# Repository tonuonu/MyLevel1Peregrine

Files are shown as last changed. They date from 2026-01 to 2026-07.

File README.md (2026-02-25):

# Peregrine

**L2 CERTIFIED** ✓ — 22 February 2026, Enköping, Sweden

Documentation for my Tripoli Level 1 and Level 2 certification rocket build using the Apogee Peregrine dual deployment kit, named **SIPSIK** after the beloved Estonian cartoon character.

**📖 Documentation Site: [tonuonu.github.io/MyLevel1Peregrine](https://tonuonu.github.io/MyLevel1Peregrine/)**

## L2 Certification Flight

| | |
|---|---|
| **Date** | 22 February 2026 |
| **Location** | Enköping, Sweden (SMRK) |
| **Motor** | AeroTech J350 |
| **Weight** | 3100 g |
| **Expected Altitude** | 1100 m |
| **Recovery** | Dual deploy, 18" + 48" electronic (CATS Vega) |
| **Certifying Authority** | Rolf Örell (TRA# 3728) |
| **Result** | **CERTIFIED** |

## L1 Certification Flight

| | |
|---|---|
| **Date** | 24 January 2026 |
| **Location** | Enköping, Sweden (SMRK) |
| **Motor** | AeroTech H128W-14A |
| **Altitude** | 140.8 m |
| **Recovery** | Motor ejection, single chute |
| **Certifying Authority** | Rolf Örell (TRA# 3728) |
| **Result** | **CERTIFIED** |

## Repository Contents

- `docs/` — MkDocs documentation source
- `openrocket/` — OpenRocket simulation files (.ork)
- `openscad/` — 3D printable parts:
  - Nose cone with CATS Vega mount
  - Motor retainer
  - Mass dummy motors (H128W, J420R) for ground testing
- `.github/workflows/` — CI for automatic deployment

## Rocket Specs

| | |
|---|---|
| **Kit** | Apogee Peregrine |
| **Length** | 175 cm |
| **Diameter** | 100 mm |
| **Motor mount** | 38mm (29mm with adapter) |
| **Flight computer** | CATS Vega |
| **Tripoli #** | 38105 |

## Hardware

Motor casings purchased from Rolf Örell:
- **38/720** — J motors (L2 certification)
- **29/180** — H motors (L1 class)

## The Story

This blue rocket teaches my daughters Liza (5) and Elsa (2) real engineering through the Estonian cartoon character Sipsik. In the cartoon, siblings build a cardboard rocket to send their toy to the moon. Now we're doing it for real.

A small "Sipsik of Sipsik" flew on the L1 certification flight — the real doll was too valuable to risk.

## Local Development

```bash
# Install MkDocs
brew install mkdocs
pip install mkdocs-material --break-system-packages

# Serve locally
mkdocs serve

# View at http://127.0.0.1:8000/MyLevel1Peregrine/
```

## Author

[Tõnu Samuel](https://www.linkedin.com/in/tonusamuel/) — Tallinn, Estonia

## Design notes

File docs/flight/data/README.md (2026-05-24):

# Flight Data — Workflow

This directory holds raw CATS Vega flight logs and the tools to turn them into charts and analysis numbers. The workflow is designed so that **next time a flight is logged, conversion just works** — no format re-discovery needed.

## Files

| File | Purpose |
|---|---|
| `flXXX.cfl` | Raw binary flight log from CATS Vega (downloaded over USB) |
| `stXXX.txt` | CATS Configurator stats export — ground-truth max values |
| `CATS_FORMAT.md` | **Binary format specification** (read this before changing the parser) |
| `generate_charts.py` | Parser + chart generator. Strict; stops cleanly on unknown record types |
| `flXXX.summary.json` | Auto-generated per-flight summary (parser output) |
| `readme.txt` | Upstream CATS Configurator notice |

## Downloading a flight log from CATS Vega

1. Connect the CATS Vega to a computer via USB while pressing the boot button (puts it in Mass Storage Controller mode)
2. The device exposes the flash filesystem — copy `flXXX.cfl` and `stXXX.txt` for the flight(s) of interest
3. Drop both files into this directory

Up to 50 flight logs and 50 stats files are exposed per the firmware limit.

## Generating charts and analysis

```bash
cd docs/flight/data/
python generate_charts.py flXXX.cfl ../flightN_charts.png \
    --motor "AeroTech XYZ" \
    --title "Flight #N — L? Certification" \
    --json flXXX.summary.json
```

The script prints flight summary numbers (apogee, max velocity, max accel, FSM transitions) to stdout and writes the chart PNG and a JSON summary. Cross-check the JSON against `stXXX.txt` — they should agree to within rounding.

## Reproducing past flights

```bash
# L1 (Flight #1, 24 January 2026, AeroTech H128W-14A)
python generate_charts.py fl001.cfl ../flight1_charts.png \
    --motor "AeroTech H128W-14A" --title "Flight #1 — L1 Certification" \
    --json fl001.summary.json

# L2 (Flight #2, 22 February 2026, AeroTech J350)
python generate_charts.py fl002.cfl ../flight2_charts.png \
    --motor "AeroTech J350" --title "Flight #2 — L2 Certification" \
    --json fl002.summary.json
```

Expected output (verified against `stXXX.txt`):

| Flight | Apogee | Max velocity | Max accel |
|---|---|---|---|
| #1 (L1) | 141.58 m | 46.24 m/s | 4.5 g |
| #2 (L2) | 986.43 m | 172.56 m/s | 17.5 g |

## When the parser breaks

If `generate_charts.py` reports `Unknown rec_type_raw=0x…` and stops before the end of the file:

1. The CATS firmware has added or changed a record type
2. Read `CATS_FORMAT.md` for the format model
3. Find the new type definition in [catsystems/cats-embedded `recorder.hpp`](https://github.com/catsystems/cats-embedded/blob/main/flight_computer/src/flash/recorder.hpp)
4. Add an entry to the `RECORDS` dict in `generate_charts.py` (name, payload size, struct format string)
5. **Also update `CATS_FORMAT.md`** — that file is the spec, not a docstring

**Do NOT** make the parser slide bytes on unknown types. That hides the problem and produces silent garbage downstream — see `tasks/lessons.md` for the history.

## Format reference

See [`CATS_FORMAT.md`](CATS_FORMAT.md) for the complete binary format spec, FSM state enum, and hardware notes. That file is the authoritative reference — kept separate from any script so it cannot be erased by an accidental docstring edit.

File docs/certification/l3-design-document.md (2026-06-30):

# L3 Certification Design Document

**Candidate**: Tõnu Samuel (TRA# 38105)
**TAP Member #1**: Rolf Örell (TRA# 3728)
**TAP Member #2**: TBD
**Date**: February 2026 (Draft)
**Status**: DRAFT — Not yet submitted for TAP review

---

## Table of Contents

1. [Project Overview](#1-project-overview)
2. [Airframe Construction Details](#2-airframe-construction-details)
3. [Bill of Materials](#3-bill-of-materials)
4. [Recovery System](#4-recovery-system)
5. [Recovery Electronics Schematic](#5-recovery-electronics-schematic)
6. [Motor](#6-motor)
7. [Stability Analysis](#7-stability-analysis)
8. [Flight Simulations](#8-flight-simulations)
9. [Fin Flutter Analysis](#9-fin-flutter-analysis)
10. [Construction Documentation](#10-construction-documentation)
11. [L2 Flight Log](#11-l2-flight-log)
12. [Pre-Flight Checklist](#12-pre-flight-checklist)
13. [Safety Analysis](#13-safety-analysis)

---

## 1. Project Overview

### 1.1 Objective

Tripoli Level 3 high-power certification using a scratch-built rocket with a single AeroTech M1350W-PS motor, dual-deployment recovery controlled by dual redundant electronics.

### 1.2 Rocket Summary

| Parameter | Value |
|---|---|
| Name | TBD |
| Designer/Builder | Tõnu Samuel |
| Construction | Scratch-built |
| Length | TBD |
| Diameter | TBD |
| Dry weight (no motor) | TBD |
| Liftoff weight (with motor) | TBD |
| Motor | AeroTech M1350W-PS (75mm, 5178 N-s) |
| Recovery | Dual deploy, dual redundant electronics, servo-actuated spring release (mechanism TBD) |
| Expected altitude | TBD |
| Number of fins | TBD |
| Fin material | Spectrum PC CF (3D printed polycarbonate + carbon fiber) |

### 1.3 Design Philosophy

- Minimum motor class (barely M at 5178 N-s) to keep velocities and forces manageable
- Progressive flight testing on J and L motors before cert flight
- 3D printed fin can in PC CF with carbon rod reinforcement for flutter resistance
- Dual redundant electronics as required by Tripoli L3 rules
- Servo-actuated spring release instead of black powder ejection charges — mechanism under evaluation (C-latch with tongue or dual-half bayonet)
- Symmetric design: identical parts for both redundancy halves to simplify manufacturing and spares
- Single-use motor to avoid reloadable hardware risk

---

## 2. Airframe Construction Details

*Per Tripoli L3 requirement 1.a.i: Dimensioned drawings*

### 2.1 General Arrangement Drawing

*TODO: Dimensioned side-view drawing showing all major sections and dimensions*

- Overall length
- Body tube OD/ID
- Nose cone length and shape
- Fin dimensions and positions
- CP and CG locations marked
- Electronics bay location
- Recovery section layout
- Motor mount position and length
- Separation mechanism locations

### 2.2 Body Tube

| Parameter | Value |
|---|---|
| Material | TBD (commercial prebuilt tube) |
| Outer diameter | TBD |
| Inner diameter | TBD |
| Wall thickness | TBD |
| Total length | TBD |

### 2.3 Nose Cone

| Parameter | Value |
|---|---|
| Type | TBD (ogive/Von Kármán/conical) |
| Material | TBD (3D printed or commercial) |
| Length | TBD |
| Shoulder length | TBD |

Electronics may be housed in the nose cone — see section 2.8.

### 2.4 Fin Can Assembly

The fin can is 3D printed by the candidate using OpenSCAD for parametric design and Bambu P1S for printing.

| Parameter | Value |
|---|---|
| Material | Spectrum PC CF (polycarbonate + carbon fiber) |
| Number of fins | TBD |
| Fin shape | TBD |
| Root chord | TBD |
| Tip chord | TBD |
| Span | TBD |
| Thickness | TBD |
| Sweep angle | TBD |
| Reinforcement | Carbon rod channels (2× per fin, at 25% and 60% chord) |
| Infill | 70% |
| Print orientation | TBD |

**Multi-part assembly**: The fin can body is printed in multiple sections (each ≤250mm tall, Bambu P1S limit with AMS) and bonded together. Fins are printed individually and bonded to the assembled can.

### 2.5 Centering Rings and Bulkheads

| Component | Material | Dimensions | Notes |
|---|---|---|---|
| Forward centering ring | TBD | TBD | |
| Aft centering ring | TBD | TBD | |
| E-bay forward bulkhead | TBD | TBD | |
| E-bay aft bulkhead | TBD | TBD | |

### 2.6 Motor Mount

| Parameter | Value |
|---|---|
| Motor tube ID | 75mm |
| Motor tube material | TBD |
| Length | TBD (≥622mm for M1350W-PS) |
| Motor retention | TBD |

### 2.7 Motor Adapters

For pre-certification test flights:

| Adapter | For Motor | Inner Diameter |
|---|---|---|
| 75→54mm | AeroTech L1000W-18A | 54mm |
| 75→38mm | AeroTech J420R | 38mm |

### 2.8 Electronics Bay

| Parameter | Value |
|---|---|
| Location | TBD — either mid-body or nose cone |
| Length | TBD |
| Sled material | TBD |
| Switch access | External key switches (2×, one per system) |

**Nose cone option**: Placing electronics in the nose cone simplifies wiring (all forward), and the electronics mass helps CG stay forward for stability. Trade-off is accessibility and nose cone structural requirements.

**Mid-body option**: Traditional e-bay between recovery sections. Easier access, standard approach.

*TODO: Decide based on airframe layout and CG analysis.*

### 2.9 Servo and Battery Enclosures in Parachute Bay

The separation servos and their batteries must be located near the separation joints, which are inside the parachute storage bays. To prevent parachutes and shock cords from snagging on electronics hardware:

**Wall-hugging enclosure concept**: A 3D printed fairing mounts the servo and battery flush against the inner tube wall. The enclosure has a smooth, snag-free outer surface facing inward, so the parachute slides past without catching. Essentially a streamlined bump on the inside of the body tube.

| Parameter | Value |
|---|---|
| Material | Spectrum PC CF (same as other printed parts) |
| Contents per enclosure | 1 servo + 1 battery (or battery located elsewhere with wiring routed through) |
| Enclosures per joint | 2 (one per FC system, 180° apart) |
| Total enclosures | 4 (2 joints × 2 per joint) |
| Design | Parametric OpenSCAD, matched to tube ID curvature |
| Mounting | Bonded or mechanically fastened to tube wall |
| Outer surface | Smooth, radiused edges, no exposed screws or wires |

*TODO: Determine whether battery is co-located with servo in the enclosure or kept in the main e-bay with wiring routed to the servo. Co-location is simpler (shorter wires, fewer failure points) but adds mass in the parachute bay.*

### 2.10 Rail Guides

| Parameter | Value |
|---|---|
| Type | TBD |
| Quantity | TBD |
| Positions | TBD |

---

## 3. Bill of Materials

*Per Tripoli L3 requirement 1.a.ii*

### 3.1 Airframe Components

| Item | Specification | Quantity | Source |
|---|---|---|---|
| Body tube | TBD (commercial prebuilt) | TBD | TBD |
| Nose cone | TBD | 1 | TBD |
| Fin can body (printed) | Spectrum PC CF | 1 set | Printed by candidate |
| Fins (printed) | Spectrum PC CF | TBD | Printed by candidate |
| Carbon reinforcement rods | 2.0mm carbon rod | TBD | TBD |
| Centering rings | TBD | TBD | TBD |
| Motor mount tube | 75mm ID | 1 | TBD |
| Motor retainer | TBD | 1 | TBD |
| E-bay structure | TBD | 1 | TBD |
| Bulkheads | TBD | 2 | TBD |
| Rail guides | TBD | TBD | TBD |
| Shock cord | TBD | TBD | TBD |
| Quick links / hardware | TBD | TBD | TBD |

### 3.2 Recovery Components

| Item | Specification | Quantity | Source |
|---|---|---|---|
| Drogue parachute | TBD size | 1 | TBD |
| Main parachute | TBD size | 1 | TBD |
| Separation springs | TBD | TBD per joint | TBD |
| C-hooks (printed) | Spectrum PC CF, identical parts | 2 per joint (4 total) | Printed by candidate |
| Tongues (printed) | Spectrum PC CF, servo-actuated | 2 per joint (4 total) | Printed by candidate |
| Servo wall-hugging enclosures (printed) | Spectrum PC CF, matched to tube ID | 4 total (2 per joint) | Printed by candidate |
| Servos (separation) | TBD | 4 total (1 per tongue) | TBD |
| Tether cord (mechanism retention) | TBD | As needed | TBD |

### 3.3 Electronics

| Item | Specification | Quantity | Source |
|---|---|---|---|
| Primary flight computer | Custom (CATS Vega clone, improved) | 1 | Built by candidate |
| Backup flight computer | CATS Vega (original) or second custom clone | 1 | TBD |
| Battery (primary) | TBD | 1 | TBD |
| Battery (backup) | TBD | 1 | TBD |
| Key switch (primary) | TBD | 1 | TBD |
| Key switch (backup) | TBD | 1 | TBD |

### 3.4 Motor

| Item | Specification | Quantity | Source |
|---|---|---|---|
| AeroTech M1350W-PS | 75mm single-use DMS | 1 | TBD (requires L3 to purchase — sourced via TAP) |

---

## 4. Recovery System

*Per Tripoli L3 recovery requirements: parachute recovery required, dual deployment allowed with apogee destabilization event*

### 4.1 Recovery Architecture

Dual deployment using servo-actuated spring release mechanisms, controlled by dual redundant electronics:

| Event | Altitude | Device | Action |
|---|---|---|---|
| Apogee | Apogee detection | Primary FC + Backup FC | Either servo retracts its tongue → C-hook opens → springs push sections apart → drogue deploys |
| Main | TBD (e.g., 300m AGL) | Primary FC + Backup FC | Either servo retracts its tongue → C-hook opens → springs push sections apart → main deploys |

### 4.2 Separation Mechanism Concept

Instead of black powder ejection charges, separation is achieved mechanically:

1. **Springs** are preloaded between body sections during assembly, providing separation force
2. **Retention mechanism** (two identical C-latches at 180° apart) holds the sections together against the spring preload during flight
3. **Servos** retract tongues on command from the flight computer
4. Once either tongue is retracted, the C-hook at that position is an open hook holding nothing — one remaining C-latch cannot hold against the spring force alone → sections separate axially

**Why not black powder ejection charges?**

The conventional approach for HPR recovery separation uses black powder (BP) ejection charges. This design uses mechanical separation instead, for two reasons:

1. **Legal constraint (Estonia)**: Black powder is classified as an explosive under Estonian law. The candidate has no legal basis to possess even small quantities. Rocket motors are classified separately as pyrotechnics and are legally permissible. This is a hard constraint — BP-based separation is not an option for a builder based in Estonia
2. **Electronics protection**: BP charges deposit soot and combustion residue throughout the recovery bay. This rocket carries custom-built flight computers that are expensive and difficult to replace. Mechanical separation keeps the interior clean

**Additional advantages of mechanical separation**:

- Repeatable and testable — same force every time, no charge sizing uncertainty
- No hot gas near parachutes — no Nomex protectors needed
- No e-matches — simpler wiring, no igniter reliability concerns
- No pressure spike — gentler on airframe and recovery harness

### 4.3 Separation Mechanism Candidates

Two leading candidates are under evaluation. Both share the same core principle: two identical halves per joint, each controlled by one FC system, either half's release alone causes separation. The selection will be made after prototyping and discussion with Rolf.

#### Option A: C-Latch with Tongue (Preferred)

A tongue-and-groove style latch. At the separation joint, C-shaped hooks are fixed to the body sections, opening toward each other. A servo-actuated tongue fills the gap in each C-hook, locking it closed. The servo retracts the tongue to release. The analogy is a door with two locks on opposite sides and no hinges — open either lock and the whole thing falls apart.

**Operating principle:**

```
    SIDE VIEW — CROSS-SECTION AT ONE C-LATCH
    (looking at the tube wall from inside)

    LOCKED (tongue inserted)          RELEASED (tongue retracted)

    Body A       Body B               Body A       Body B
    ┌────┐       ┌────┐              ┌────┐       ┌────┐
    │    └─┐ ┌─┘    │              │    └─┐ ┌─┘    │
    │      │T│      │              │      │ │      │  ← C-hooks are open,
    │    ┌─┘ └─┐    │              │    ┌─┘ └─┐    │    nothing bridges them
    └────┘       └────┘              └────┘       └────┘

    C-hooks: passive, fixed to body sections, opening toward each other
    T = tongue: servo-actuated, fills the C-gap to lock
    Servo retracts tongue sideways → C-hooks have open mouths → sections separate

    TOP VIEW — FULL JOINT (looking down into tube)

                 C-latch #1 (FC #1)
                    ┌─┐
              ╭─────┤T├─────╮
             │     └─┘     │
         Body A             Body B
             │     ┌─┐     │
              ╰─────┤T├─────╯
                    └─┘
                 C-latch #2 (FC #2)

    Two C-latches at 180° apart
    Each has its own servo-actuated tongue
    Either tongue retracted → that C-hook is open → other latch can't hold → separation
```

**Terminology:**

| Term | Description |
|---|---|
| **C-hook** | Passive C-shaped bracket fixed to a body section. The open mouth faces the mating body section. Carries axial load only when the tongue is present to close the gap |
| **Tongue** | Servo-actuated piece that fills the C-hook gap, closing it into a closed loop. Connected to the servo arm. When retracted, the C-hook is an open hook holding nothing |
| **C-latch** | One complete latch assembly: two opposing C-hooks (one per body section) + one tongue + one servo. Two C-latches per joint, at 180° apart |

**How it works:**

- **Locked**: Tongue fills the C-hook gap on both sides. The C-hooks on Body A and Body B face each other with the tongue bridging both, creating a closed structural loop. Axial loads (thrust, drag) are transferred through the C-hook walls and tongue in compression/shear
- **Released**: Servo retracts the tongue sideways. Both C-hooks at that position now have open mouths — there is nothing connecting Body A to Body B at that point. Like removing a lock from a door with no hinges: one remaining lock on the opposite side cannot hold the door against the spring preload → sections push apart axially
- **Binary release guarantee**: Tongue in = closed loop carrying load. Tongue out = open hooks holding nothing. No force-balancing needed. The geometry guarantees separation when the tongue is retracted

**Key design properties:**

| Property | Value |
|---|---|
| C-latches per joint | 2 (at 180° apart) |
| Tongues per joint | 2 (one per C-latch, servo-actuated) |
| Total C-latches | 4 (2 joints × 2 latches) |
| Total tongues | 4 |
| Servos total | 4 (one per tongue) |
| Unique parts to design | **1 C-hook** (same part on both body sections) + **1 tongue** (connected to servo arm) |
| FC #1 controls | Tongue at C-latch #1 (drogue joint) + Tongue at C-latch #1 (main joint) |
| FC #2 controls | Tongue at C-latch #2 (drogue joint) + Tongue at C-latch #2 (main joint) |

**Advantages:**

- **Binary release**: Tongue in = locked, tongue out = open hook. No force balancing, no partial engagement, no "can one latch hold?" uncertainty. The geometry guarantees separation when a tongue is retracted
- **Simple servo action**: Linear tongue retraction (sideways). Servo arm pulls the tongue out of the C-gap. No rotation, no twist, no complex linkage
- **Passive C-hooks**: The C-hooks are just geometry on the body sections — no moving parts, no mechanism to jam. All the action is in the tongue, which is a simple sliding piece
- **Strong when locked**: With tongue inserted, the C-hook + tongue form a closed structural loop. Axial loads transfer through the loop in compression/shear — well-understood load path
- **Symmetric**: Same C-hook part printed multiple times. Same tongue design used everywhere
- **Full axial separation**: Body sections push apart completely, standard parachute deployment geometry
- **No tube cutout**: Latches are at the separation plane, no weakening of the body tube

**Concerns:**

- **Tongue retraction force**: Tongue must slide out cleanly under servo pull. Under axial flight loads, the tongue may be loaded in compression or shear — friction between tongue and C-hook surfaces could resist retraction. Smooth surfaces, correct tolerances, and lubrication needed. The tongue geometry should be designed so axial loads do not clamp the tongue (loads should transfer through the C-hook walls, not through friction on the tongue)
- **C-hook strength**: The printed C-hooks must handle flight loads without cracking or deforming. Wall thickness, infill, and print orientation critical. PC CF should have adequate strength, but needs analysis
- **Tongue retention during flight**: Tongue must not slide out under vibration or G-loads. The servo holds the tongue in position, and the retraction direction should be perpendicular to the primary axial load so flight loads don't tend to push the tongue out. Additional options: friction fit, slight taper, or detent
- **Servo torque**: Must overcome tongue friction + any detent force. Linear pull via servo arm — calculate required force and arm geometry
- **Tolerances**: C-hook gap and tongue dimensions must match. 3D printing tolerance for the gap width and tongue thickness. Print and test iterate
- **Cold weather**: Tongue friction and servo performance at -10 to -20°C
- **Tethering**: After tongue retraction, the tongue remains attached to the servo arm (inherently tethered). C-hooks are fixed to their body sections (inherently tethered)

#### Option B: Symmetric Dual-Half Bayonet (Alternative)

The bayonet joint is split into two identical halves, positioned 180° apart. Each half is an independent rotary latch controlled by its own servo and FC system.

- **Locked**: Both bayonet halves engaged. Together they carry full flight loads
- **Released**: Either servo releases its half (rotary or linear disengage). One half alone cannot resist the spring preload → sections separate axially
- Each half carries ~50% of axial load when both engaged, but cannot resist spring force alone

**Advantages:**

- Full axial separation
- Bayonet lugs are strong load-bearing surfaces
- One part design, print four copies

**Concerns:**

- Lug geometry is the critical design parameter — must hold flight loads with two halves but release under spring force with one half. This is the key weakness vs. the C-latch: the bayonet requires careful force-balancing between lug engagement depth and spring force, whereas the C-latch release is binary (tongue in/out)
- Must not creep under vibration — needs detent or servo holding torque
- Bayonet parts stay in the bay after release — potential tangle with parachute

#### Common Design Elements

Both options share:

| Element | Description |
|---|---|
| **Identical halves** | Same part printed multiple times. One design, multiple prints |
| **Spring deployment** | Preloaded springs push body sections apart after release |
| **Wall-hugging servo enclosures** | Servo + battery in smooth 3D printed fairings against tube wall (see section 2.9) |
| **4 servos total** | One per latch half, 2 per joint, 2 joints |
| **Tethering** | All released parts remain attached to a rocket section |
| **FC mapping** | FC #1 controls latch #1 at both joints, FC #2 controls latch #2 at both joints |

### 4.4 Redundancy Analysis

Applies to both mechanism options:

| Scenario | Result |
|---|---|
| Both FCs fire normally | Both latches release → clean separation |
| FC #1 fires, FC #2 fails | Latch #1 releases → separation (C-latch: open hook holds nothing; bayonet: one half can't hold) |
| FC #2 fires, FC #1 fails | Latch #2 releases → separation (same logic) |
| Both FCs fail | Both latches remain locked → no separation (ballistic) |
| Servo #1 jams (mechanical) | FC #2 releases latch #2 → separation |
| Servo #2 jams (mechanical) | FC #1 releases latch #1 → separation |

True independent redundancy in both options: no single electrical or mechanical failure prevents recovery.

### 4.5 Mechanism Selection — TODO

Decision criteria for selecting between Option A (C-latch) and Option B (bayonet):

1. **Prototype both** — print test versions of each, test fit and release on a body tube section
2. **Release reliability** — C-latch has binary release (tongue in/out), bayonet requires force-balancing. This strongly favors Option A
3. **Structural analysis** — compare load capacity of C-hooks vs. bayonet lugs under flight loads
4. **Tongue retraction testing** — verify tongue retracts cleanly under realistic conditions (load, cold, vibration)
5. **TAP feedback** — discuss both with Rolf before committing
6. **Ease of field assembly** — which is simpler to set up and verify at the launch site?

Current preference: **Option A (C-latch)** due to binary release guarantee.

### 4.6 Design Challenges — TODO

Regardless of which mechanism is selected:

- **Structural analysis**: Mechanism must handle boost loads (axial: motor thrust + drag, bending: wind loads, vibration: motor resonance)
- **Spring force**: Must reliably push sections apart and deploy parachute at all expected altitudes. Validated by ground testing
- **Servo selection**: Must reliably actuate in cold weather (Swedish winter, -10 to -20°C at altitude), under vibration, after sustaining boost G-loads. Torque margin needed
- **Tolerances**: 3D printed parts have different tolerances than machined parts. Test under realistic conditions, print spares
- **Tethering**: All parts must remain attached to a rocket section. Tongues are tethered to servo arms, C-hooks are fixed to body sections. No parts may descend without a recovery system (Tripoli non-certification condition)
- **Wall-hugging enclosures**: Must not snag parachute or shock cord. Ground test with actual parachute packing
- **Discuss with Rolf early**: Non-pyro separation is less common for L3. TAP approval of the concept is needed before detailed design

### 4.7 Drogue Deployment

| Parameter | Value |
|---|---|
| Trigger | Apogee detection (barometric) |
| Mechanism | Servo-actuated release + spring separation (TBD: C-latch or bayonet) |
| Parachute | TBD size drogue |
| Descent rate under drogue | TBD m/s |
| Separation point | TBD |

### 4.8 Main Deployment

| Parameter | Value |
|---|---|
| Trigger | Altitude-based (TBD meters AGL) |
| Mechanism | Servo-actuated release + spring separation (TBD: C-latch or bayonet) |
| Parachute | TBD size main |
| Descent rate under main | TBD m/s (must not exceed 35 ft/s = 10.7 m/s per Tripoli rules) |
| Separation point | TBD |

### 4.9 Landing Velocity

| Parameter | Value |
|---|---|
| Maximum allowed | 35 ft/s (10.7 m/s) per Tripoli TUSC |
| Expected landing velocity | TBD |
| Liftoff weight | TBD |
| Main parachute Cd | TBD |

### 4.10 Redundancy Architecture

Per Tripoli L3 rules: *"Dual redundant electronics are required for all recovery events. Two completely independent and separate electronic recovery systems must be incorporated. Neither system must adversely affect the other. Redundancy means completely separate systems, including batteries, switches, avionics, and energetics."*

With servo-actuated separation, "energetics" is replaced by servo + tongue/mechanism + spring. Each system controls its own C-latch at both separation joints.

| Component | Primary System (FC #1) | Backup System (FC #2) |
|---|---|---|
| Flight computer | Custom FC (CATS Vega clone, improved) | CATS Vega (original) or second custom clone |
| Battery | Dedicated battery #1 | Dedicated battery #2 |
| Arming switch | Key switch #1 | Key switch #2 |
| Drogue release | Servo #1 → retracts tongue at C-latch #1 (drogue joint) | Servo #2 → retracts tongue at C-latch #2 (drogue joint) |
| Main release | Servo #3 → retracts tongue at C-latch #1 (main joint) | Servo #4 → retracts tongue at C-latch #2 (main joint) |

The two systems share no electrical connections. Each has independent power, switching, sensing, and servo output. Each controls one of the two C-latches at each joint. Either system alone triggers separation.

### 4.11 Motor Note

The M1350W-PS is a plugged motor — no motor ejection charge. All recovery depends entirely on the dual redundant electronic systems. There is no motor backup.

### 4.12 Considered and Rejected Alternatives

The following approaches were evaluated earlier and set aside:

- **Dual pin (without C-latch)**: Two independent pins, each pulled by one servo. Simpler mechanically, but harder to ensure one pin alone cannot hold against springs while both together resist flight loads. The C-latch solves this by making the release binary
- **Single bayonet with dual servos**: One bayonet ring, two servos rotating it in opposite directions. Cleaner single mechanism, but a jammed bayonet blocks both systems — not truly independent failure paths
- **Hybrid (bayonet + pin bypass)**: Primary via bayonet rotation, backup via pin pull releasing entire bayonet assembly. True mechanical independence, but asymmetric design — two different part types, more complex, tether management concerns
- **Hinged door**: Hatch in body tube wall with hinge pins on two sides. Pull either pin → door swings open → parachute deploys sideways. Mechanically elegant degraded mode, but the tube cutout weakens structural integrity, creates aerodynamic discontinuity, and requires sideways parachute deployment which is non-standard. The C-latch achieves the same binary release guarantee while maintaining full axial separation and no tube cutout
- **Interlocking C-loops with lateral pin**: C-shaped loops on each body section interlock like a knuckle hinge, held together by a lateral pin through both loops. Pull pin to release. Evaluated but replaced by the simpler C-latch concept where C-hooks are passive receptacles and the tongue is the only moving part

---

## 5. Recovery Electronics Schematic

*Per Tripoli L3 requirement 1.a.iii: "A wiring diagram that accurately reflects the wiring provided by the candidate from the power source, switches, and ejection charges."*

*Note: With servo-actuated separation, the wiring diagram shows servo connections instead of e-match/charge connections. Schematics of the actual flight computer internals are NOT required — only the wiring from power source, through switches, to the flight computers and servos.*

### 5.1 Wiring Diagram

*TODO: Create wiring diagram showing:*

- Battery #1 → Key switch #1 → Primary FC → Servo #1 (drogue C-latch #1 tongue) + Servo #3 (main C-latch #1 tongue)
- Battery #2 → Key switch #2 → Backup FC → Servo #2 (drogue C-latch #2 tongue) + Servo #4 (main C-latch #2 tongue)
- Physical separation between systems
- Servo connections (signal + power)
- Mechanical linkage: servo arm → tongue retraction (conceptual)

### 5.2 Primary System

| Connection | From | To |
|---|---|-----|
| Power | Battery #1 (TBD V) | Key switch #1 |
| Switched power | Key switch #1 | Primary FC power input |
| Servo channel 1 | Primary FC drogue output | Servo #1 → retracts tongue at drogue C-latch #1 |
| Servo channel 2 | Primary FC main output | Servo #3 → retracts tongue at main C-latch #1 |

### 5.3 Backup System

| Connection | From | To |
|---|---|-----|
| Power | Battery #2 (TBD V) | Key switch #2 |
| Switched power | Key switch #2 | Backup FC power input |
| Servo channel 1 | Backup FC drogue output | Servo #2 → retracts tongue at drogue C-latch #2 |
| Servo channel 2 | Backup FC main output | Servo #4 → retracts tongue at main C-latch #2 |

---

## 6. Motor

### 6.1 Motor Specifications

| Parameter | Value |
|---|---|
| Motor | AeroTech M1350W-PS |
| Type | Single-use DMS (Plugged + Smoke) |
| Diameter | 75mm |
| Length | 622mm |
| Total impulse | 5178 N-s (1% M-class) |
| Average thrust | 1357 N |
| Maximum thrust | 1766 N |
| Burn time | 3.8 s |
| Total weight | 4808 g |
| Propellant | White Lightning |
| Ejection | **Plugged — no ejection charge** |
| Certification | TRA certified, June 2014 |

### 6.2 Motor Retention

| Parameter | Value |
|---|---|
| Method | TBD |
| Rating | Must retain motor under full thrust loads |

### 6.3 Thrust-to-Weight Ratio

| Parameter | Value |
|---|---|
| Average thrust | 1357 N |
| Liftoff weight | TBD kg |
| Thrust-to-weight ratio | TBD (minimum 5:1 required) |

---

## 7. Stability Analysis

### 7.1 Center of Gravity (CG)

| Condition | CG Location (from nose tip) |
|---|---|
| Without motor | TBD |
| With motor (loaded) | TBD |
| With motor (burnout) | TBD |

### 7.2 Center of Pressure (CP)

| Method | CP Location (from nose tip) |
|---|---|
| Barrowman method | TBD |
| OpenRocket | TBD |

### 7.3 Stability Margin

| Condition | Margin (calibers) | Assessment |
|---|---|---|
| At launch (loaded) | TBD | Must be ≥1.0 cal |
| At burnout | TBD | |

*Note: CP must be marked on the rocket per Tripoli rules.*

### 7.4 Rail Exit Velocity

| Parameter | Value |
|---|---|
| Rail length | TBD |
| Rail exit velocity | TBD (must be sufficient for stable flight) |

---

## 8. Flight Simulations

*Per Tripoli L3 requirement 1.a.iv*

### 8.1 Simulation Software

| Software | Version | Purpose |
|---|---|---|
| OpenRocket | TBD | Primary flight simulation |

### 8.2 Simulation Parameters

| Parameter | Value |
|---|---|
| Motor | AeroTech M1350W (thrust curve from ThrustCurve.org) |
| Liftoff weight | TBD |
| Launch rod length | TBD |
| Launch angle | TBD |
| Wind speed | TBD (simulate range of conditions) |

### 8.3 Simulation Results

| Parameter | Value |
|---|---|
| Maximum altitude | TBD |
| Maximum velocity | TBD |
| Maximum Mach number | TBD |
| Maximum acceleration | TBD |
| Time to apogee | TBD |
| Rail exit velocity | TBD |
| Optimal drogue delay | N/A (electronic deployment) |
| Landing distance (no wind) | TBD |
| Landing distance (TBD m/s wind) | TBD |

### 8.4 Thrust Curve

*TODO: Include M1350W thrust curve plot*

### 8.5 Altitude vs. Time Plot

*TODO: Include simulation altitude plot*

### 8.6 Velocity vs. Time Plot

*TODO: Include simulation velocity plot (critical for flutter analysis)*

### 8.7 Wind Sensitivity Analysis

*TODO: Simulate at multiple wind speeds to verify landing within waiver radius*

---

## 9. Fin Flutter Analysis

### 9.1 Maximum Airspeed

From flight simulations:

| Parameter | Value |
|---|---|
| Max velocity | TBD m/s |
| Mach at max velocity | TBD |
| Altitude at max velocity | TBD |

### 9.2 Material Properties

| Property | Spectrum PC CF | Source |
|---|---|---|
| Elastic modulus (E) | TBD GPa | Datasheet / testing |
| Density | TBD g/cm³ | Datasheet |
| Poisson's ratio | TBD | Estimated |

### 9.3 Fin Geometry

| Parameter | Value |
|---|---|
| Root chord (Cr) | TBD |
| Tip chord (Ct) | TBD |
| Semi-span (b) | TBD |
| Thickness (t) | TBD |
| Taper ratio (λ = Ct/Cr) | TBD |

### 9.4 Flutter Speed Calculation

*TODO: Calculate flutter speed using NACA/Air Force flutter boundary equation and compare to maximum expected airspeed. Target safety factor ≥2.0.*

### 9.5 Carbon Rod Reinforcement

If flutter margin insufficient with PC CF alone:

| Parameter | Value |
|---|---|
| Rod diameter | 2.0-2.2mm carbon |
| Number per fin | 2 |
| Positions | 25% and 60% chord |
| Channel design | Span-wise, accessible from tab face |
| Effect on flutter speed | TBD |

---

## 10. Construction Documentation

*Per Tripoli L3 requirements: candidate shall personally assemble all assemblies, frequently communicate with TAPs, and provide photos of construction progress.*

### 10.1 Construction Log

*TODO: Dated entries with photos for each construction phase:*

- [ ] Fin can 3D printing (OpenSCAD design → 3MF export → Bambu P1S print)
- [ ] Fin printing and carbon rod installation
- [ ] Fin can assembly (bonding sections and fins)
- [ ] Motor mount assembly
- [ ] Centering ring installation
- [ ] Body tube preparation
- [ ] Separation mechanism prototype printing and testing (C-latch and bayonet)
- [ ] Mechanism selection after prototyping
- [ ] Final mechanism parts printing and fit testing
- [ ] Wall-hugging servo enclosure printing and fit testing
- [ ] Electronics bay / nose cone electronics construction
- [ ] Dual flight computer installation and wiring
- [ ] Servo installation and testing
- [ ] Recovery harness assembly
- [ ] Parachute packing and deployment test through mechanism
- [ ] Spring preload and mechanism engagement testing
- [ ] Final assembly
- [ ] Weight and CG measurements
- [ ] CP marking on airframe
- [ ] Ground test of electronics (both systems independently)
- [ ] Separation mechanism ground testing (each latch independently)

### 10.2 Construction Photos

*TODO: Photos of candidate working on each assembly per Tripoli requirement*

---

## 11. L2 Flight Log

*Per Tripoli L3 requirement: 3 flights on L2 impulse (J/K/L), at least 2 with electronic deployment. Submit with Tripoli L2-to-L3 Flight Log form.*

| Flight | Date | Motor | Impulse | Electronic Deploy | Status |
|---|---|---|---|---|---|
| 1 | 22 Feb 2026 | AeroTech J350 | J (658 N-s) | ✓ CATS Vega dual deploy | ✅ Complete |
| 2 | TBD | AeroTech J420R | J (658 N-s) | ✓ Custom FC | Planned |
| 3 | TBD | AeroTech L1000W | L (2714 N-s) | ✓ Custom FC | Planned |

Electronic deployment count: 1 of 2 minimum complete.

---

## 12. Pre-Flight Checklist

*Based on [Tripoli Pre-Flight Data Capture Form](https://www.tripoli.org/docs.ashx?id=891494) and [Pre-Flight Review Checklist](https://www.tripoli.org/content.aspx?page_id=22&club_id=795696&module_id=496546)*

### 12.1 Before Leaving Home

- [ ] Design packet (this document, approved and signed by both TAPs)
- [ ] Signed Universal Certification Form (UCF) — top portion completed
- [ ] Completed Pre-Flight Data Capture Form
- [ ] L2-to-L3 Flight Log Form (with 3 flights documented)
- [ ] Rocket fully assembled and inspected
- [ ] Motor (M1350W-PS)
- [ ] Igniter (FirstFire)
- [ ] Batteries charged (2×, one per system)
- [ ] Key switches and keys (2×)
- [ ] Spare C-hooks, tongues, and servos
- [ ] Tools for field assembly

### 12.2 At Launch Site — Before Assembly

- [ ] Present design packet to certifying TAP
- [ ] Present completed Data Capture Form
- [ ] TAP reviews predicted flight characteristics
- [ ] Verify compliance with TUSC and FAR 101.25
- [ ] Verify launch site dimensions support required safe distances

### 12.3 Assembly and Arming

- [ ] Assemble motor per instructions
- [ ] TAP inspection of motor assembly
- [ ] Install motor in rocket with retention
- [ ] Pack drogue parachute
- [ ] Pack main parachute
- [ ] Preload separation springs
- [ ] Insert tongues into C-hooks at drogue joint (both C-latches)
- [ ] Insert tongues into C-hooks at main joint (both C-latches)
- [ ] Verify tongue engagement at both joints (visual + tactile check)
- [ ] Verify all tethers attached (tongues tethered to servo arms)
- [ ] Connect servo mechanisms to tongues
- [ ] Connect primary FC wiring and servos (#1, #3)
- [ ] Connect backup FC wiring and servos (#2, #4)
- [ ] Arm primary system (key switch #1)
- [ ] Verify primary FC status (LED/beep)
- [ ] Arm backup system (key switch #2)
- [ ] Verify backup FC status (LED/beep)
- [ ] Final visual inspection
- [ ] Place on launch rail

### 12.4 Post-Flight

- [ ] Recover rocket (all parts)
- [ ] Present to TAP as recovered
- [ ] TAP inspects for excessive damage
- [ ] TAP determines certification result
- [ ] If successful: TAP signs UCF
- [ ] Candidate emails signed UCF to Tripoli HQ

---

## 13. Safety Analysis

### 13.1 Failure Modes

| Failure Mode | Mitigation | Consequence |
|---|---|---|
| Motor CATO | Single-use motor, proper assembly | Non-certification |
| Motor retention failure | Adequate retention hardware, inspection | Non-certification |
| Primary electronics failure | Backup system retracts tongue at C-latch #2 → separation | Successful recovery |
| Backup electronics failure | Primary system retracts tongue at C-latch #1 → separation | Successful recovery |
| Both electronics fail | Design for reliability, ground test | Non-certification (ballistic descent) |
| Single servo failure | Other system's servo retracts its tongue → separation | Successful recovery |
| Both servos fail on same joint | Ground testing, servo selection, cold testing | Failed separation |
| Tongue stuck (friction/binding) | Smooth surfaces, lubrication, tolerances, cold testing; other tongue still retracts | Successful recovery (degraded) |
| C-hook cracked/broken | PC CF strength analysis, print orientation, infill, test loads | Structural failure at joint |
| Spring insufficient | Ground testing at various temperatures, margin in spring force | Incomplete separation |
| Premature tongue retraction (vibration/G) | Servo holds tongue in position, retraction direction perpendicular to axial loads, detent | Premature separation during boost |
| Tether tangle with parachute | Tether routing, length management, ground test | Tangled recovery |
| Parachute snags on servo enclosure | Wall-hugging smooth fairing, ground test with actual packing | Failed deployment |
| Fin flutter | Flutter analysis, carbon reinforcement, progressive test flights | Structural failure |
| Unstable flight | Stability analysis, CP/CG verification, OpenRocket sim | Unsafe flight |
| Parachute tangle | Proper packing, ground test | Failed recovery |

### 13.2 Risk Mitigation Through Testing

| Test | Purpose | When |
|---|---|---|
| C-latch prototype | Print and test C-hook + tongue engagement and release | Early prototyping |
| Bayonet prototype | Print and test bayonet half engagement/release | Early prototyping |
| Mechanism selection | Compare prototypes, select winner | After prototyping |
| Tongue retraction force measurement | Quantify force needed to retract tongue under load and no-load | After mechanism selection |
| Servo enclosure fit test | Verify parachute slides past without snagging | During construction |
| Separation bench test (both tongues) | Verify spring separates when both tongues retracted | During construction |
| Redundancy test (tongue #1 only) | Verify retracting tongue #1 alone causes separation | During construction |
| Redundancy test (tongue #2 only) | Verify retracting tongue #2 alone causes separation | During construction |
| Cold temperature test | Verify servo and mechanism operation at -10 to -20°C | During construction |
| Vibration/shake test | Verify tongues don't retract under simulated flight loads | During construction |
| Tether deployment test | Verify tethered tongues don't tangle with parachute | During construction |
| Flight #2 (J420R) | Validate airframe, electronics, separation mechanism in flight | Before L flight |
| Flight #3 (L1000W) | Stress test at higher loads and speeds | Before M flight |
| Electronics ground test | Verify both systems detect apogee/altitude correctly | Before each flight |

### 13.3 Compliance

| Requirement | Compliance Method |
|---|---|
| Tripoli Unified Safety Code (TUSC) | Design review, simulation |
| FAR 101.25 | Altitude prediction within waiver |
| Waiver radius | Wind simulation, dual deploy for tight landing |
| Landing velocity ≤ 35 ft/s | Parachute sizing calculation |
| Dual redundant electronics | Two independent systems, each controlling one C-latch tongue |
| No untethered components | Tongues tethered to servo arms, C-hooks fixed to body sections |
| CP marked on rocket | External marking |

---

## Appendices

### A. OpenRocket Simulation Files

*TODO: Include .ork file or simulation output*

### B. OpenSCAD Design Files

*TODO: Include .scad source for fin can, fins, C-hooks, tongues, and servo enclosures*

### C. Thrust Curve Data

*TODO: Include M1350W RASP file from ThrustCurve.org*

### D. Material Datasheets

*TODO: Spectrum PC CF filament datasheet*

### E. Flight Computer Documentation

*TODO: Custom FC schematic, PCB layout, firmware overview*

### F. Separation Mechanism Design

*TODO: Detailed drawings of selected separation mechanism, including:*

- C-hook geometry (OpenSCAD parametric design)
- Tongue dimensions and material
- Tongue retraction force analysis (friction, detent, servo torque margin)
- Spring selection and force calculations
- Servo selection and arm geometry for linear tongue retraction
- Anti-vibration tongue retention design (servo holding + optional detent)
- Wall-hugging servo enclosure design
- Redundancy verification test results (each tongue independently)
- Tether routing plan (tongues tethered to servo arms)
- Assembly and preload procedure
- Print settings and tolerance measurements
- Cold weather test results
- Prototype comparison results (C-latch vs. bayonet)

### G. Forms

- [Universal Certification Form (UCF)](https://www.tripoli.org/docs.ashx?id=859597)
- [Pre-Flight Data Capture Form](https://www.tripoli.org/docs.ashx?id=891494)
- [L2 to L3 Flight Log Form](https://www.tripoli.org/docs.ashx?id=1566254)

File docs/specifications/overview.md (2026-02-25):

# Apogee Peregrine Overview

The Peregrine is a high-power dual-deployment rocket designed by Apogee Components. It features distinctive swept-back curved fins and is intended for fliers who already have (or are pursuing) Level 1 certification.

## Key Features

- **Dual Deployment Ready**: Includes electronics bay, dual parachutes, and all hardware
- **Distinctive Fin Design**: Swept-back curved birch plywood fins extend below the base tube
- **Large Size**: 68.8" length makes it highly visible during flight
- **Traditional Construction**: Kraft paper tubes, plywood centering rings, wooden components
- **Detailed Instructions**: Apogee provides comprehensive step-by-step build documentation

## Primary Specifications

| Specification | Value | Metric |
|---|---|---|
| Overall Length | 68.8" | 175 cm |
| Body Diameter | 4.0" | 98mm |
| Nose Cone Length | 19.8" exposed | 50 cm |
| Nose Cone Type | 5:1 Ogive | - |
| Dry Weight | ~5+ lbs | ~2.3+ kg |
| Motor Mount | 38mm | - |
| Fin Count | 3 | - |
| Fin Material | Birch plywood | - |

## Nose Cone Details

The PNC-98 nose cone:

- 5:1 length-to-diameter ogive shape
- Made from polypropylene plastic (flexible, impact resistant)
- Requires adhesion promoter before priming/painting
- Super-strong attachment loop for shock cord

## Recovery System

| Component | Size |
|---|---|
| Main Parachute | 48" (122 cm) nylon |
| Drogue Parachute | 18" (45 cm) nylon |
| Shock Cord | Fluorescent orange tubular nylon |
| Chute Protectors | 12" Nomex (2 included) |

## Motor Recommendations

### For L2 Certification (38mm J motors)

- AeroTech J350 (used for SIPSIK L2 flight)
- AeroTech J420R

### For L1 Certification (38mm H motors, or 29mm with adapter)

- AeroTech H128W (used for SIPSIK L1 flight)
- AeroTech H100W
- AeroTech H180W  
- AeroTech H210 Redline
- AeroTech H220T
- Cesaroni H180

### Test Flights (29mm with adapter)

- AeroTech G80T (max non-HP motor)
- Various G motors with 29/38mm adapter

!!! note "Certification Note"
    Apogee recommends single deployment with motor ejection for L1 certification for simplicity. SIPSIK used motor ejection for L1 and dual deployment (CATS Vega) for L2 — both successful.

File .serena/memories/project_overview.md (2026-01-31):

# MyLevel1Peregrine Project Overview

## Status: L1 CERTIFIED ✓

Certification achieved 24 January 2026 at Enköping, Sweden. L2 written exam passed 27 January 2026.

## Certification Flight Summary
- **Date**: 24 January 2026
- **Location**: Enköping, Sweden (SMRK event)
- **Motor**: AeroTech H128W-14A
- **Altitude**: 140.8 m (predicted 208 m - extra weight from dual flight computers)
- **Recovery**: Motor ejection (pivoted from planned electronic dual-deploy due to cold weather)
- **Certifying Authority**: Rolf Örell (TRA# 3728, first European Tripoli Prefect)
- **Helpers**: Peter Steen, Anton Vannesjö

## Original Launch Plan
- **Date**: Saturday, 24 January 2026 (Sunday backup for weather)
- **Location**: Långtora Airfield, Sweden ([SMRK event](https://smrk.space/kalender/raketflygdag-langtora_20260124))
- **Motor**: AeroTech H128W (29mm, White Lightning) - purchased locally in Sweden

## Purpose
Documentation repository for a Tripoli Level 1 certification rocket build using the Apogee Peregrine dual deployment kit. Kit purchased from Sierra Fox Hobbies (Italy) - listed as L2 but L1 capable. Designed for CRO (Club Range Officer) review with calculations and formulas for verification, plus photo documentation of build methods to judge structural rigidity.

## Tech Stack
- **Documentation**: MkDocs with Material theme
- **Math rendering**: MathJax for LaTeX formulas
- **Diagrams**: Mermaid for flowcharts
- **Hosting**: GitHub Pages static site

## Rocket Configurations

| Config | Length | Recovery | Stability | Use |
|---|---|---|---|-----|
| **L1** | 126 cm | Motor ejection | ~1.0 cal (with ballast) | Certification |
| **L2** | 175 cm | CATS Vega dual-deploy | 3.69 cal | After L1 cert |

## L1 Flight Configuration (Actual)
Based on certification form, flew full-length configuration:
- Length: 175 cm
- Diameter: 100 mm
- Liftoff weight: 2350 g
- CG: 115 cm from nose tip
- CP: 130 cm from nose tip
- Stability: ~1.5 calibers
- Motor: AeroTech H128W-14A
- Recovery: Motor ejection (pivoted from planned electronic dual-deploy)
- Delay: ~8s (14s factory - 8s drilled + 2s disk in tool)

## Key Rocket Specifications (Full L2)
- Length: 68.8" (175 cm)
- Diameter: 4.0" (102mm OD, 99.1mm ID)
- Motor mount: 38mm (29mm with adapter)
- Weight: ~1900g L2, ~2100g L1 (with ballast)
- Dual deployment capable

## Known Discrepancies (Packaging vs Website)
- Skill Level: packaging says 4, website says 3
- Height: packaging says "Over 65"", actual is 68.8"

## L2 Certification Planning
- **Target date**: 7 February 2026 (tentative, pending motor delivery)
- **Motor**: AeroTech J420R-14A ordered from Space Rocket Technology (Germany), shipping to Peter Steen in Sweden
- **Written exam**: Passed 27 January 2026, Certificate #2343
- **Hardware**: 38/720 and 29/180 casings purchased from Rolf Örell

## Motor Hardware
Purchased Aerotech reloadable casings from Rolf Örell:
- **38/720** — 38mm, 720 N-s max, for J motors (L2)
- **29/180** — 29mm, 180 N-s max, for H motors (L1)

## Transport Constraint
Tallink passenger ferries have blanket ban on dangerous substances. Contacted them directly - no procedure exists, no exceptions. Motors must be purchased/shipped within Sweden.

## Key Decisions
- **Why Sweden**: Daughter in Stockholm, boat discounts, local motor purchase, no ferry transport of motors
- **Flight computer**: CATS Vega (open source, Altium format)
- **Motor retainer**: 3D printed ASA from Thingiverse
- **Rail guides**: Kit 6.2mm buttons installed, 3D printed backup
- **Color**: Blue (Sipsik-themed for teaching daughters Liza 5 and Elsa 2)
- **Payload**: Small "Sipsik of Sipsik" flew on L1 - real doll too valuable to risk

## Structure
- `docs/` - MkDocs markdown content
- `docs/blog/` - Flight reports and updates
- `docs/certification/` - L1 certified, L2 planning
- `docs/configurations.md` - L1 vs L2 comparison
- `docs/photos/` - Build and flight photos, certificates
- `docs/decisions/` - Decision log entries
- `openrocket/` - Simulation files
  - `PeregrineL1.ork` - L1 configuration
  - `PeregrineL2.ork` - L2 configuration
- `openscad/` - 3D printable parts
  - `PeregrineNoseCone.scad` - Simple ballast-only nose cone
  - `PeregrineNoseConeElectronics.scad` - Nose cone with CATS Vega mount
  - `H128W.scad` - Mass dummy motor for ground testing
  - `J420R.scad` - Mass dummy motor for ground testing
- `mkdocs.yml` - Site configuration

## Mass Dummy Motors
PLA prints at 100% infill are 20-25% lighter than real motors. Drill 8mm hole and insert steel rod (~0.4 g/mm) for weight adjustment:
- H128W: 208g real weight, needs ~100-130mm rod
- J420R: 635g real weight, needs ~300-400mm rod

## External Resources
- Rocketry Forum: Wally Ferrer build thread (Feb 2021) - detailed photos
- Rocketry Forum: Stability measurement thread - contains Peregrine.ork file
- OpenRocket displays rounded values; actual diameter is 10.16cm not 10.2cm
- Thingiverse #6780161: Motor retainer + rail guides
- CATS Vega: Open source flight computer (catsystems.io)

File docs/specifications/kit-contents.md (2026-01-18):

# Kit Contents

The Apogee Peregrine kit includes all components needed for a complete dual-deployment rocket build.

## Kit Identification

| Info | Value |
|---|---|
| Kit Number | 04998 |
| Face Card P/N | 39101 |
| Barcode | 656779049988 |
| Age Rating | 18+ |

!!! note "Packaging vs Website Discrepancies"
    | Item | Packaging | Website/Actual |
    |------|-----------|----------------|
    | Skill Level | 4 | 3 |
    | Height | "Over 65"" | 68.8" (175 cm) |

## Airframe Components

| Component | Description |
|---|---|
| Body Tubes | Heavy-wall kraft paper, white overwrap |
| Coupler Tubes | For joining sections |
| Nose Cone (PNC-98) | 5:1 ogive, polypropylene plastic |
| Centering Rings | Aviation plywood |
| Bulkheads | Plywood |

## Fin Assembly

| Component | Description |
|---|---|
| Fins (3) | Laser-cut birch plywood, swept-back curved shape |
| Fin Alignment | Interlocking support structure |

## Motor Mount

| Component | Description |
|---|---|
| Motor Tube | 38mm diameter, heavy wall |
| Centering Rings | Plywood, sized for 38mm to 98mm |
| Thrust Block | Included (remove for longer motors) |

!!! note "Motor Retention"
    Motor retention is NOT included. Apogee recommends:
    
    - AeroPack 38L Engine Retainer
    - Fins & Fire 38mm Retainer
    - Or use masking tape (traditional method)

## Electronics Bay (E-Bay)

| Component | Description |
|---|---|
| E-Bay Tube | 98mm diameter coupler |
| Bulkheads | Plywood with eyebolt holes |
| Sled | Plywood mounting platform |
| Threaded Rod | Single rod design (lighter than dual-rod) |
| Switch Band | For arming switch mounting |
| Hardware | Wing nut, washers, eyebolts |

## Recovery System

| Component | Size/Description |
|---|---|
| Main Parachute | 48" ripstop nylon, printed pattern |
| Drogue Parachute | 18" ripstop nylon |
| Shock Cord (Main) | Shorter cord, fluorescent orange tubular nylon |
| Shock Cord (Drogue) | Longer cord, fluorescent orange tubular nylon |
| Chute Protectors | 12" Nomex, reusable (2 included) |
| Quick Links | For easy parachute attachment |

## Finishing

| Component | Description |
|---|---|
| Vinyl Decals | 2 full sheets (color + metallic silver) |
| Rail Buttons | For launch rail guidance |
| Plastic Rivets | For securing e-bay to airframe |

## Not Included (Required)

- Motor retention system
- Altimeter/flight computer
- Ejection charge canisters (for dual deploy)
- Black powder or CO2 cartridges
- E-matches or igniters
- Epoxy (5-minute and 30-minute recommended)
- Paint and primer
- Motors

## Optional Accessories

- 29/38mm Motor Adapter (for test flights on G motors)
- AeroPack Motor Retainer
- GPS Tracker
- Keychain camera with aerodynamic shroud

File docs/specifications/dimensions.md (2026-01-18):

# Dimensions

## Overall Dimensions

```
┌─────────────────────────────────────────────────────────────────────────┐
│                                                                         │
│  ◄──────────────────────── 68.8" (175 cm) ────────────────────────────► │
│                                                                         │
│     ╭──────╮                                                            │
│    ╱        ╲    ┌──────────────────────────────────────────┐   ╲      │
│   ╱   NOSE   ╲   │              BODY TUBE                   │    ╲╲╲   │
│   ╲   CONE   ╱   │              + E-BAY                     │    ╱╱╱   │
│    ╲        ╱    └──────────────────────────────────────────┘   ╱      │
│     ╰──────╯                                                            │
│                                                                         │
│  ◄── 19.8" ──►   ◄─────────────────────────────────────────────────►   │
│   (exposed)                                                             │
│                                                                         │
└─────────────────────────────────────────────────────────────────────────┘

                              ◄── 4.0" (98mm) ──►
                                  (diameter)
```

## Detailed Measurements

| Dimension | Imperial | Metric |
|---|---|---|
| Total Length | 68.8" | 175 cm |
| Body Diameter (OD) | 4.0" | 98mm |
| Nose Cone (exposed) | 19.8" | 50 cm |
| Nose Cone Shape | 5:1 Ogive | - |
| Motor Tube (ID) | 38mm | - |
| Motor Tube Length | 11" | 28 cm |

## Fin Dimensions

The Peregrine features distinctive swept-back curved fins that extend below the body tube base.

!!! info "Fin Geometry"
    The curved fin profile requires freeform or spline definition in OpenRocket.
    RockSim file from Apogee contains accurate fin geometry.

| Parameter | Value |
|---|---|
| Fin Count | 3 |
| Material | Birch plywood |
| Attachment | Through-the-wall (TTW) |
| Extends Below Tube | Yes |

## Electronics Bay Dimensions

| Dimension | Value |
|---|---|
| E-Bay Diameter | 98mm (4") |
| Coupler OD | Fits 98mm body tube |
| Sled Width | Fits inside coupler |

## Recovery Bay Volumes

These volumes are important for calculating ejection charges:

| Bay | Location | Notes |
|-----|---|---|
| Drogue Bay | Forward (nose to e-bay) | 18" drogue + protector |
| Main Bay | Aft (e-bay to fins) | 48" main + protector |

!!! note "Volume Calculation"
    Use RockSim or OpenRocket to calculate exact bay volumes.
    See [Ejection Charges](../calculations/ejection-charges.md) for charge sizing.

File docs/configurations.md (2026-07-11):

# Rocket Configurations

## Overview

The Apogee Peregrine is designed for dual-deployment but can be flown in simplified configuration.

!!! success "L1 & L2 Certification Complete"
    **L2 flight (22 Feb 2026):** Full-length configuration (175cm), dual deploy electronic recovery (CATS Vega). See [Certification](certification/index.md) for details.
    **L1 flight (24 Jan 2026):** Full-length configuration (175cm), motor ejection recovery.

### Configurations Flown

| Level | Configuration | Recovery | Rocket Length |
|---|---|---|---|
| **L1** | Full length, no e-bay deployment | Motor ejection | 175 cm |
| **L2** | Full length, dual deploy | Electronic dual-deploy + motor backup | 175 cm |

## L1 Configuration (as flown)

**Flight:** 24 January 2026

### Hardware
- Full-length airframe with e-bay (carried CATS Vega for logging only)
- Single 48" main parachute
- Motor ejection delay
- Nose ballast for stability (~300-600g epoxy)

### Recovery Sequence
1. Motor burns out
2. Delay charge burns (selected delay time)
3. Ejection charge fires
4. Nose cone separates, main chute deploys
5. Rocket descends under single parachute

### Why This Configuration
- Fewer failure modes for first certification
- Swedish safety rules required ejection charge testing — motor ejection as fallback
- Traditional L1 approach
- Proves basic HPR competency

### Stability Challenge
Removing e-bay deployment function moves risk profile. See [OpenRocket Analysis](../simulations/openrocket.md).

## L2 Configuration (as flown)

**Flight:** 22 February 2026

### Hardware
- Full airframe with electronics bay
- CATS Vega flight computer controlling deployment
- 18" drogue parachute (upper section)
- 48" main parachute (lower section)
- Motor delay charge (14s, unmodified) as safety backup

### Recovery Sequence
1. Motor burns out
2. Rocket coasts to apogee
3. **Apogee:** Flight computer fires drogue charge (electronic #1)
4. Drogue deploys, fast descent (~15-20 m/s)
5. **Lower altitude:** Flight computer fires main charge (electronic #2)
6. Main chute deploys, slow descent (~5 m/s)
7. Rocket lands close to pad

Motor's original 14s delay charge left unmodified as a third, independent backup ejection source.

### Why Dual Deployment
- **Required by 500m landing radius constraint** — simulations showed that with main-only recovery from ~1000m, any wind above 4 m/s would carry the rocket beyond the allowed radius
- Smaller landing footprint
- Reduced wind drift
- What Peregrine is designed for

## Component Summary

| Component | L1 Config | L2 Config |
|---|---|---|
| Body tube | Full length | Full length |
| Electronics bay | ✓ Installed (logging only) | ✓ Controls deployment |
| CATS Vega | Data logging only | ✓ Controls deployment |
| Drogue chute | ❌ None | ✓ 18" at apogee |
| Main chute | ✓ 48" | ✓ 48" at lower altitude |
| Electronic charges | ❌ None | ✓ 2× black powder |
| Motor backup charge | ✓ Primary deployment | ✓ 14s safety backup |
| Deployment | Motor delay | Electronic + motor backup |
| Nose ballast | ✓ Included | ✓ Included |

## Flight Parameters

| Parameter | L1 (actual) | L2 (actual) |
|---|---|---|
| Rocket mass (no motor) | ~2350g (liftoff) | ~3100g (liftoff) |
| Length | 175 cm | 175 cm |
| Motor | H128W-14A | J350 |
| Apogee | 141.6 m | 986.4 m |

## References

- [L1 Configuration Decision](../decisions/l1-configuration.md)
- [Flight Computer Decision](../decisions/flight-computer.md)
- [OpenRocket Stability Analysis](../simulations/openrocket.md)
- [Weight Budget](../calculations/l1-weight-budget.md)

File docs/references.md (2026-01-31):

# External References

## Kit Purchase

Purchased from [Sierra Fox Hobbies](https://www.sierrafoxhobbies.com/en/high-power-rockets/2109-peregrine-hpr-apogee.html) (Italy) - listed as L2 kit but also L1 capable (flies on H motors). Was the only kit in stock from their [HPR selection](https://www.sierrafoxhobbies.com/en/19-high-power-rockets).

## Community Resources and discussions related to the Apogee Peregrine.

## Rocketry Forum Threads

### Build Threads

- [Apogee Peregrine Build](https://www.rocketryforum.com/threads/apogee-peregrine-build.164948/) - Wally Ferrer (Feb 2021)
    - Detailed photo documentation of complete build
    - Tips: CA glue on tube edges, Kevlar string method for centering ring removal
    - Rocketpoxy fillet technique with fondant ball
    - Badass Rocketry fin guides mentioned

### Technical Discussions

- [Trying to find an OpenRocket file for the Apogee Peregrine](https://www.rocketryforum.com/threads/trying-to-find-an-openrocket-file-for-the-apogee-peregrine.166457/) - laxmax51 (May 2021)
    - Discussion about importing RockSim .rkt files into OpenRocket
    - **Key tip**: OpenRocket can open RockSim .rkt files directly, then save as .ork
    - Note: Fancy fin shapes may not import perfectly

- [Stability measurement as a caliber or as a percentage](https://www.rocketryforum.com/threads/stability-measurement-as-a-caliber-or-as-a-percentage.177665/) - MetricRocketeer (Jan 2023)
    - Discusses caliber vs percentage stability display in OpenRocket
    - **Contains Peregrine.ork file** shared by user
    - Explains apparent CP/CG calculation discrepancies are due to OpenRocket rounding display values
    - Actual values: diameter 10.16cm (not 10.2cm), CG 113.79cm, CP 130.25cm

!!! note "OpenRocket Rounding"
    OpenRocket displays rounded values but calculates with full precision. This explains why manual calculations from displayed values may not match the stability shown.

!!! tip "RockSim to OpenRocket"
    OpenRocket is **free open-source software** that can import RockSim .rkt files directly. Apogee provides RockSim files for their kits - these can be opened in OpenRocket and saved as .ork files. Fin shapes may need minor cleanup after import.

## Flight Electronics

- [CATS Vega](https://www.catsystems.io/vega) - Open source flight computer (ordered)
- [CATS Ground Station](https://www.catsystems.io/ground-station-1) - Telemetry receiver (ordered)

## 3D Printed Parts

- [38mm Motor Retainer + Rail Guides](https://www.thingiverse.com/thing:6780161) - Thingiverse model for motor retention (printed in ASA) and backup rail guides

## Motors

### H128W (L1 Certification)

- [AeroTech H128W on ThrustCurve](https://www.thrustcurve.org/motors/AeroTech/H128W/) - Technical specs, thrust curve data

| Spec | Value |
|---|---|
| Diameter | 29mm |
| Total Impulse | 172.9 Ns |
| Avg Thrust | 128 N |
| Burn Time | 1.3 s |
| Propellant | White Lightning |
| Case | RMS-29/180 |
| Total Mass | 208 g |

### J420R (L2 Certification)

- [AeroTech J420R on ThrustCurve](https://www.thrustcurve.org/motors/AeroTech/J420R/) - Technical specs, thrust curve data
- [Space Rocket Technology Shop](https://www.spacerockettechnology-shop.de/en/J420R-14A.html) - German retailer

| Spec | Value |
|---|---|
| Diameter | 38mm |
| Total Impulse | 658 Ns |
| Avg Thrust | 420 N |
| Burn Time | 1.6 s |
| Propellant | Redline |
| Case | RMS-38/720 |
| Total Mass | 635 g |

!!! note "Motor Classifications"
    - **H class**: 160-320 Ns total impulse
    - **J class**: 640-1280 Ns total impulse
    - **EU Pyrotechnics**: P2 (requires specialist knowledge)

## Launch Events

- [SMRK - Svenska ModellRaketKlubben](https://smrk.space/) - Swedish Model Rocket Club
- [Raketflygdag Långtora 24 Jan 2026](https://smrk.space/kalender/raketflygdag-langtora_20260124) - L1 certification flight

## Certification

- [Tripoli Rocketry Association](https://www.tripoli.org/) - Certification organization
- [Tripoli Lifetime Members](https://tripoli.clubexpress.com/content.aspx?page_id=22&club_id=795696&module_id=494497) - Includes Rolf Örell (TRA# 3728), first European Tripoli Prefect

## Manufacturer Resources

- [Apogee Components - Peregrine Product Page](https://www.apogeerockets.com/Rocket-Kits/Skill-Level-3-Kits/Peregrine)
- [Peregrine Instruction Manual (PDF)](https://www.apogeerockets.com/downloads/PDFs/04998-Peregrine-instructs.pdf) - Official assembly instructions
- [Apogee Peak of Flight Newsletter](https://www.apogeerockets.com/education/newsletter)

## Regulatory

- [EU Directive 2013/29/EU](https://eur-lex.europa.eu/eli/dir/2013/29/oj) - Pyrotechnic articles regulation (P1/P2 categories)

## Related Threads

- Completing the trifecta: the Apogee Peregrine coming together (novahobbies, Jul 2025)
- Apogee Nike-Hercules build thread (spullen, Nov 2024)
- "455" - Apogee Zephyr for TRA Level 1 (MikeMcP, Nov 2025)

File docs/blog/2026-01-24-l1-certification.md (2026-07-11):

# L1 Certification: Mission Accomplished

*24 January 2026, Enköping, Sweden*

## Sipsik Goes to the Sky

In the Estonian cartoon, a girl named Anu and her brother Mart build a cardboard rocket hoping to send their beloved toy Sipsik to the moon. Now my daughters Liza (5) and Elsa (2) are learning how we *actually* send rockets to the sky.

The blue rocket named **SIPSIK** flew today.

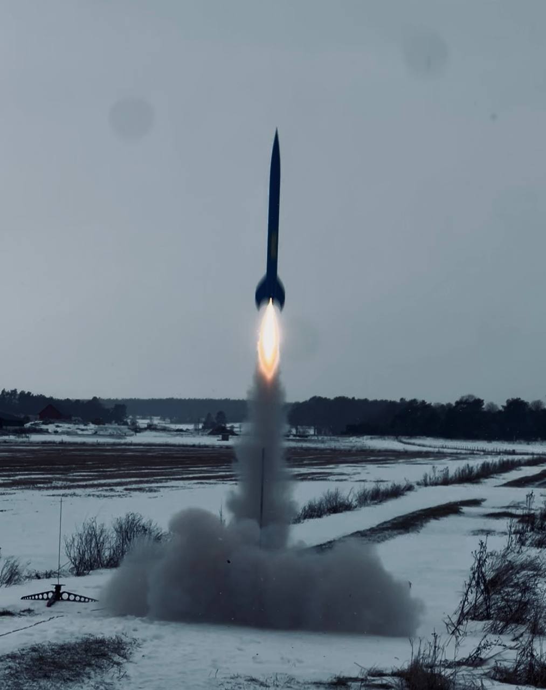
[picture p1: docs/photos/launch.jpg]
Launch


## The Road to Sweden

Why Sweden for an Estonian's L1 certification? Practical reasons:

1. **Motor logistics** - Rocket motors cannot be transported on Tallink passenger ferries (blanket ban on dangerous substances). Must purchase locally.
2. **Family** - Daughter lives in Stockholm
3. **Active club** - SMRK (Swedish Model Rocket Club) runs regular launch events

Took the car on the Tallinn-Stockholm ferry, then drove to Enköping.

The launch was on 24 January as originally planned.

## Launch Day

Temperature around -5°C. Snow on the ground. Classic Swedish winter.

### The Pivot

I arrived with a CATS Vega flight computer and a friend's data logger, planning dual deployment with electronic ejection. Then reality set in:

1. **Cold weather** - Around -5°C
2. **Swedish safety rules** - Ejection charges must be ground-tested before flight
3. **Certification flight** - Keep it simple, reduce variables

Decision: pivot to motor ejection with single parachute recovery.

### Delay Adjustment Math

The H128W-14A comes with 14 second factory delay. For my predicted 208m apogee, I calculated needing about 6 seconds.

**Plan**: Drill out 8 seconds → 14 - 8 = 6s delay

**Reality**: Unknowingly had the +2s disk in the delay adjustment tool during drilling.

**Actual delay**: ~8 seconds (14 - 8 + 2 = 8)

Lesson learned: know your tools before launch day.

### Flight

First attempt. The certificate comment reads "Beautiful low flight" - acknowledging both the successful flight and the lower-than-expected altitude.

**CATS Vega recorded: 141.58 meters**

Lower than the predicted 208m. The likely cause: unplanned extra weight. Two flight computers, extra LiPo batteries, and various small items added up. Weight matters - roughly 30% altitude reduction.

The ~8 second delay (instead of planned 6) meant deployment happened past apogee during descent. Still successful - the rocket was descending slowly enough.

### Recovery

Landed nearby, easy to find. No damage to rocket.

### The Payload

We had a small Sipsik doll on board. I explained to Liza that her real doll is too valuable to risk - what if the rocket falls down? - so this is the "Sipsik of Sipsik", representing her real one.

She was delighted.

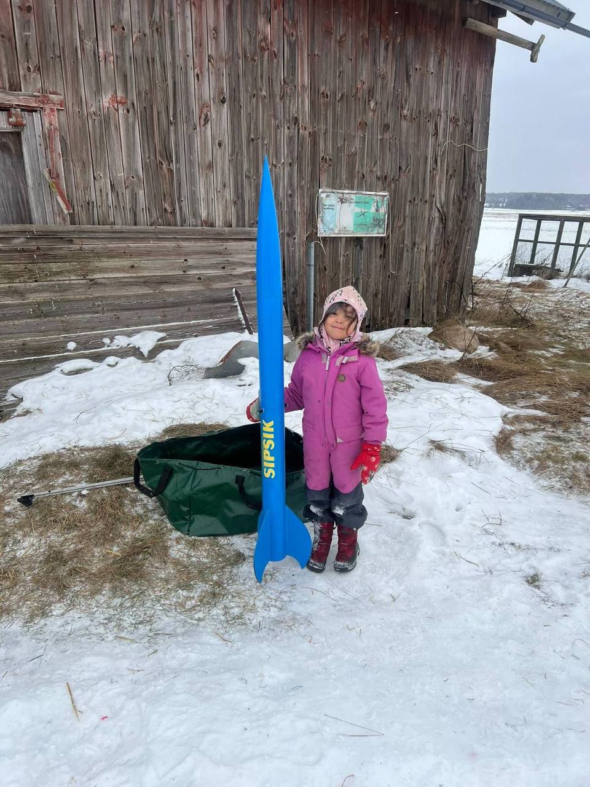
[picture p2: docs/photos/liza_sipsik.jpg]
Liza with SIPSIK


## The Certification

Rolf Örell signed my certificate. When he looked at my TRA number - 38105 - he noted it's grown tenfold since his own number: 3728.

Rolf is significant in Tripoli history:

- First Tripoli Prefect in Europe
- [Tripoli Lifetime Member](https://tripoli.clubexpress.com/content.aspx?page_id=22&club_id=795696&module_id=494497)

Special thanks also to **Peter Steen** and **Anton Vannesjö** for their help and guidance throughout the day.

## Lessons Learned

1. **Know your tools** - The Aerotech delay adjustment tool has components (like the +2s disk) that affect the result. Understand everything before launch day.

2. **Swedish launch requirements** - Ejection charges require ground testing. Plan for motor ejection as fallback, or arrive prepared to test.

3. **Weight budget discipline** - Every "small" addition compounds. Two flight computers instead of one, extra batteries, extra hardware. The ~500g over budget cost 30% altitude.

4. **Motor procurement** - Tallink passenger ferries have blanket ban on dangerous substances. No procedure exists, no exceptions. For future Swedish launches: buy motors locally or find cargo transport alternatives.

5. **Simplify for certification** - The goal is successful flight, not maximum complexity. Pivoting to motor ejection was the right call.

## What's Next

Five days after the L1 flight, I passed the Tripoli L2 written exam:

| Field | Value |
|---|---|
| Date | 27 January 2026 |
| Certificate # | 2343 |

Next milestone: L2 certification flight with a J, K, or L motor. Target date: 7 February 2026.

Motor ordered (AeroTech J420R-14A), casings purchased (38/720, 29/180). Now waiting for shipping confirmation.

The journey continues.

---

## Flight Data Summary

| Parameter | Value |
|---|---|
| Date | 24 January 2026 |
| Location | Enköping, Sweden |
| Event | SMRK Launch Day |
| Motor | AeroTech H128W-14A |
| Rocket | Apogee Peregrine "SIPSIK" |
| Length | 175 cm |
| Diameter | 100 mm |
| Liftoff weight | 2350 g |
| Predicted altitude | 208 m |
| Actual altitude | 141.58 m |
| Recovery | Motor ejection, single chute |
| Certifying authority | Rolf Örell (TRA# 3728) |
| Result | **L1 CERTIFIED** |

## Tools for Home Testing

For ground testing at home, I 3D printed mass-equivalent motor dummies:

| Motor | Real Weight | Dummy Material |
|---|---|---|
| H128W | 208 g | PLA 100% infill + steel rod |
| J420R | 635 g | PLA 100% infill + steel rod |

PLA prints come out 20-25% light. An 8mm hole allows inserting steel rod (~0.4 g/mm) for weight adjustment:

- H128W: ~100-130mm of 8mm rod needed
- J420R: ~300-400mm of 8mm rod needed

Useful for verifying CG position, testing fit, and practicing handling without pyrotechnics.

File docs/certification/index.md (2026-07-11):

# Certification

## Status: L2 CERTIFIED ✓

**Tripoli Level 2 - Certified 22 February 2026**
**Tripoli Level 1 - Certified 24 January 2026**

## Tripoli Membership

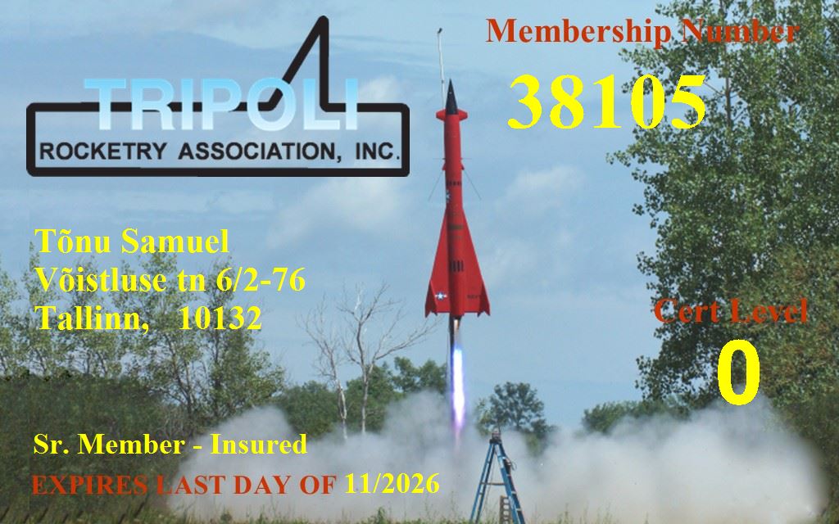
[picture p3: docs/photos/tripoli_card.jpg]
Tripoli Membership Card


| Field | Value |
|---|---|
| Organization | Tripoli Rocketry Association |
| Member Number | 38105 |
| Status | L2 Certified |
| Expires | November 2026 |

---

## L2 Certification Flight

### Flight Video

<video controls width="100%">
  <source src="../photos/l2_certification_flight.mp4" type="video/mp4">
</video>

### Flight Details

| Parameter | Value |
|---|---|
| Date | 22 February 2026 |
| Location | Enköping, Sweden |
| Organization | SMRK (Swedish Model Rocket Club) |
| Motor | AeroTech J350 |
| Result | **Successful** |

### Rocket Configuration

| Parameter | Value |
|---|---|
| Kit | Apogee Peregrine |
| Length | 175 cm |
| Diameter | 100 mm |
| Liftoff weight | 3100 g |
| CG | 115 cm from nose tip |
| CP | 130 cm from nose tip |
| Expected altitude | 1100 m |
| Actual altitude | **986.43 m** (CATS Vega) |
| Max velocity | 172.56 m/s (≈ Mach 0.50) |
| Max acceleration | 17.5 g |

See [Flight #2 Analysis](../flight/flight2-analysis.md) for full telemetry analysis.

### Recovery Configuration

Dual deployment was required by the 500m landing radius constraint. Simulations showed that with main-only recovery from ~1000m, any wind above 4 m/s would carry the rocket beyond the allowed radius.

Triple-redundant ejection system:

- **Electronic #1 (CATS Vega)**: 18" drogue parachute at apogee
- **Electronic #2 (CATS Vega)**: 48" main parachute at lower altitude
- **Motor backup**: Original 14s factory delay left unmodified as independent safety charge

### Electronics

| Device | Purpose |
|---|---|
| CATS Vega | Flight computer, dual deployment control (2 pyro channels) |

### L2 Written Examination

| Field | Value |
|---|---|
| Passed | 27 January 2026 |
| Certificate # | 2343 |

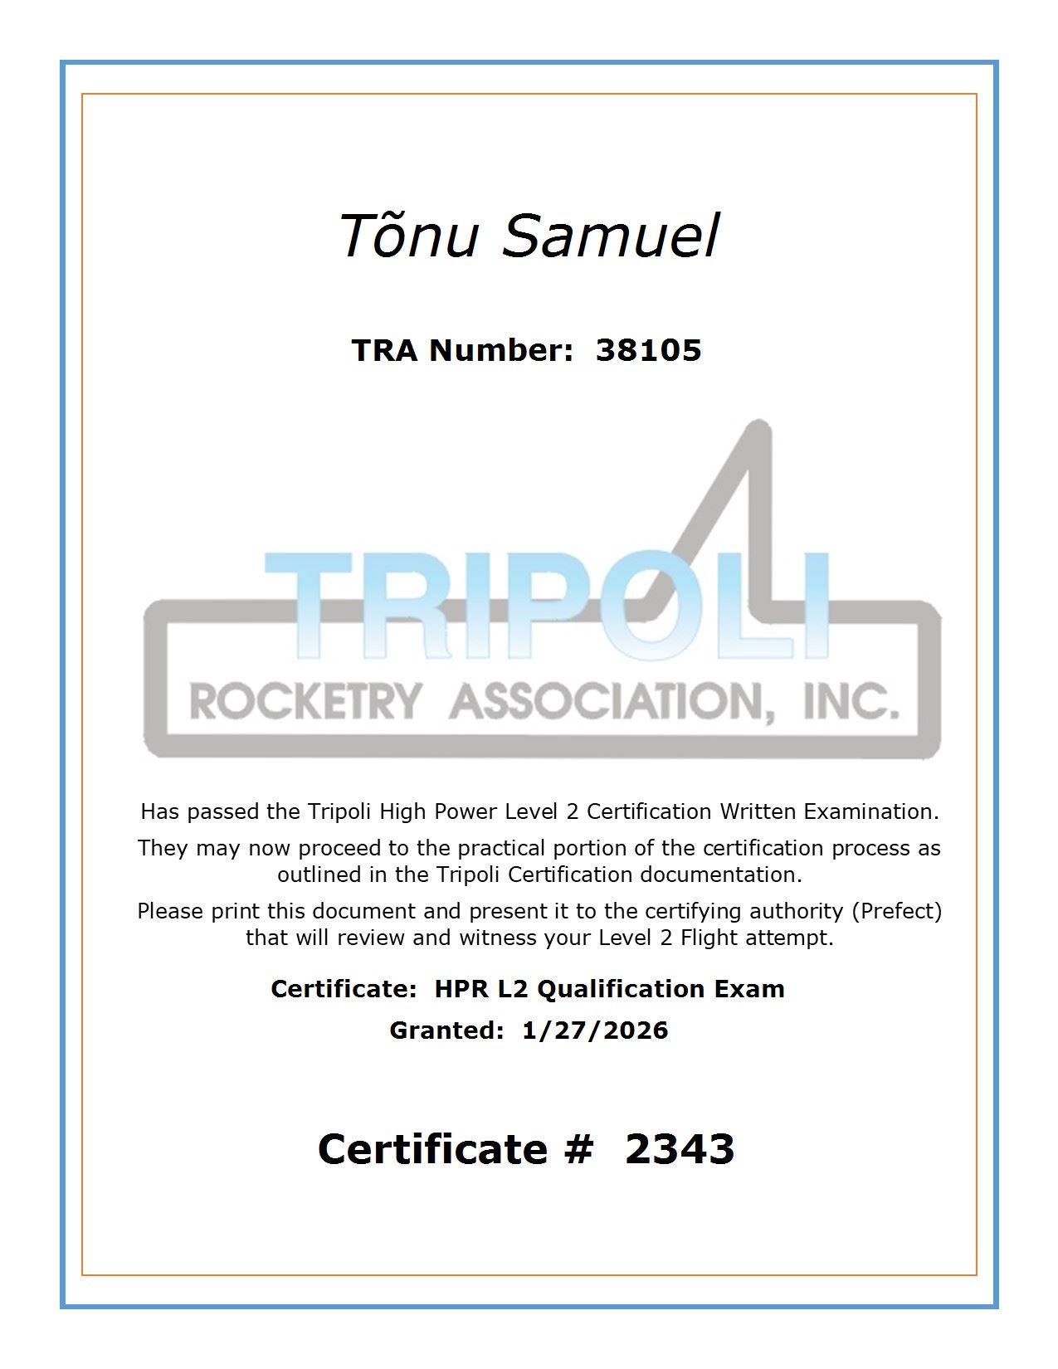
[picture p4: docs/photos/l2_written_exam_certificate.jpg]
L2 Written Exam Certificate


### Certifying Authority

| Field | Value |
|---|---|
| Name | Rolf Örell |
| TRA # | 3728 |
| Role | Tripoli Prefect |

### Official Documents

[Download L2 Certification Form (PDF)](../photos/l2_certification_form.pdf)

---

## L1 Certification Flight

### Flight Details

| Parameter | Value |
|---|---|
| Date | 24 January 2026 |
| Location | Enköping, Sweden |
| Organization | SMRK (Swedish Model Rocket Club) |
| Motor | AeroTech H128W-14A |
| Result | **Successful** |

### Rocket Configuration

| Parameter | Value |
|---|---|
| Kit | Apogee Peregrine |
| Length | 175 cm |
| Diameter | 100 mm |
| Liftoff weight | 2350 g |
| CG | 115 cm from nose tip |
| CP | 130 cm from nose tip |
| Stability margin | 15 cm (~1.5 calibers) |

### Flight Data

| Parameter | Predicted | Actual |
|---|---|---|
| Apogee | 208 m | **141.58 m** |
| Recovery | Dual electronic | Motor ejection |

The lower actual altitude was likely due to additional unplanned weight (two flight computers, LiPo batteries, etc.) beyond the original weight budget.

### Electronics

| Device | Purpose | Notes |
|---|---|---|
| CATS Vega | Primary flight computer | Data logging only - not used for deployment |
| Friend's logger | Backup data logging | Additional altitude verification |

### Recovery Configuration

Originally planned dual deployment with electronic ejection. Pivoted to motor ejection on launch day due to:

1. Cold weather conditions
2. Swedish safety rules requiring ejection charge testing before flight
3. Simplified approach for certification flight

**Delay adjustment**: H128W-14A has 14s factory delay. Calculated 6s needed for 208m apogee. Drilled out 8 seconds, but unknowingly had +2s disk in delay adjustment tool. Actual delay ~8 seconds - still successful deployment past apogee.

### Certifying Authority

| Field | Value |
|---|---|
| Name | Rolf Örell |
| TRA # | 3728 |
| Role | Tripoli Prefect |

Rolf is one of Tripoli's [Lifetime Members](https://tripoli.clubexpress.com/content.aspx?page_id=22&club_id=795696&module_id=494497) and reportedly the first Tripoli Prefect in Europe.

### Official Documents

[Download L1 Certification Form (PDF)](../photos/l1_certification_form.pdf)

---

## What's Next: L3

L1 and L2 served as verification that the fundamentals were understood correctly. L3 is a different challenge — building a rocket from scratch rather than using a kit.

| Requirement | Status |
|---|---|
| Current L2 certification | ✓ |
| TAP member #1 | Rolf Örell (confirmed) |
| TAP member #2 | TBD |
| Scratch-built rocket | Design phase |
| Documentation package | Not started |
| Review flight | Not scheduled |

---

## Acknowledgments

Special thanks to those who helped make both certifications possible:

- **Rolf Örell** - Certifying authority for L1 and L2
- **Peter Steen** - Launch support and guidance
- **Anton Vannesjö** - Launch support and guidance

## Lessons Learned

### L1
1. **Know your tools** - The Aerotech delay adjustment tool has a +2s disk; understand all components before launch day
2. **Swedish launch requirements** - Ejection charge testing required; plan for motor ejection as fallback
3. **Weight matters** - Additional electronics increased weight beyond budget, reducing altitude by ~30%
4. **Motor procurement** - Cannot transport motors on Tallink passenger ferries (blanket ban on dangerous substances); must purchase locally in Sweden or find alternative transport

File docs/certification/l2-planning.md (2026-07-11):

# L2 Certification

## Status: CERTIFIED ✓

**Certified 22 February 2026** at Enköping, Sweden.

## Timeline

| Date | Milestone |
|---|---|
| 27 January 2026 | L2 written exam passed (Certificate #2343) |
| 22 February 2026 | L2 certification flight — **Successful** |

## Motor

Originally ordered an AeroTech J420R-14A reload from [Space Rocket Technology](https://www.spacerockettechnology-shop.de/) (Germany) in late January, to be shipped to Peter Steen in Sweden. A DHL shipping label (CD042602182DE) was created on 4 February 2026, but the package was never actually picked up — no tracking movement after three weeks.

Rolf Örell had some ~25-year-old AeroTech J350 reloads in stock and offered one for the certification flight. It worked perfectly.

| Parameter | Value |
|---|---|
| Motor | AeroTech J350 (~25-year-old reload from Rolf Örell) |
| Casing | 38/720 (38mm, 720 N-s max) |

### Hardware

Aerotech reloadable motor casings purchased from Rolf Örell:

| Casing | Diameter | Max Impulse | Use |
|---|---|---|-----|
| **38/720** | 38mm | 720 N-s | J350 (L2), future J motors |
| **29/180** | 29mm | 180 N-s | H128W (L1), future H motors |

## Rocket Configuration

Apogee Peregrine "SIPSIK" in full L2 configuration:

| Parameter | Value |
|---|---|
| Length | 175 cm |
| Diameter | 100 mm |
| Liftoff weight | 3100 g |
| CG | 115 cm from nose tip |
| CP | 130 cm from nose tip |
| Expected altitude | 1100 m |
| Actual altitude | 986.43 m (CATS Vega, see [Flight #2 Analysis](../flight/flight2-analysis.md)) |
| Recovery | Dual deploy, 18" + 48" electronic |
| Flight computer | CATS Vega |

## Requirements

Per Tripoli L2 certification:
- [x] Current L1 certification
- [x] Pass L2 written exam
- [x] Successfully fly and recover rocket using J, K, or L motor
- [x] Witnessed by Prefect, TAP, or Board member

## Logistics

Same as L1: car on Tallinn-Stockholm ferry, drive to Enköping. Motor purchased/shipped within Sweden (Tallink ferry ban on dangerous substances).

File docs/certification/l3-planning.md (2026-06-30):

# L3 Certification Planning

## Status: DESIGN PHASE

L1 and L2 were verification that fundamentals were understood correctly — kit-based flights with known parameters. L3 is a different challenge: designing and building a rocket from scratch.

## Requirements

Per [Tripoli L3 certification rules](https://www.tripoli.org/Level3):

- [x] Current L2 certification
- [ ] **3 flights on L2 impulse range** (J/K/L motors), documented in Tripoli Flight Log (L2 to L3)
- [ ] **At least 2 of those flights must use electronic deployment** (electronic flight controller controlling parachute ejection — motor-ejected chute with electronic release does NOT count)
- [ ] Written project report reviewed by 2 TAP members before flight
- [ ] Scratch-built rocket (no kits)
- [ ] Successfully fly and recover using M, N, or O motor
- [ ] Witnessed and approved by 2 TAP members

### TAP Committee

| Role | Name | Status |
|---|---|---|
| TAP member #1 | Rolf Örell (TRA# 3728) | Confirmed |
| TAP member #2 | TBD | Rolf to introduce |

## Flight Progression

Incremental approach: build the L3 airframe early, fly it on progressively larger motors to validate the design before the certification flight.

| # | Motor | Diameter | Adapter | Airframe | Purpose | Electronic | Status |
|---|---|---|---|---|---|---|---|
| 1 | AeroTech J350 | 38mm | — | Peregrine | L2 certification | ✓ CATS Vega | ✅ Done |
| 2 | AeroTech J420R | 38mm | 75→38mm | L3 airframe | Test new airframe, electronic deploy #2 | ✓ Custom FC | Planned |
| 3 | AeroTech L1000W | 54mm | 75→54mm | L3 airframe | Stress test at higher impulse, electronic deploy #3 | ✓ Custom FC | Planned |
| 4 | AeroTech M1350W-PS | 75mm | None | L3 airframe | **L3 certification flight** | ✓ Custom FC | Planned |

### Flight #2: J420R in L3 Airframe

Thrust-to-weight check: J420R average thrust 420N, 5:1 minimum ratio → max liftoff mass 8.56 kg. The L3 airframe will be heavier than the Peregrine but without the M-class motor. Need to keep dry weight + adapter + J420R motor weight under 8.5 kg. May be tight — requires weight estimate once airframe design is more mature.

### Flight #3: L1000W Stress Test

The AeroTech L1000W-18A is the primary candidate for the L-class stress test flight:

| Parameter | Value |
|---|---|
| Designation | HP-L1000W |
| Diameter | 54mm |
| Length | 635mm |
| Total impulse | 2714 N-s (mid L-class) |
| Average thrust | 1000 N |
| Max thrust | 1261 N |
| Burn time | 2.7 s |
| Total weight | 2194 g |
| Propellant | White Lightning |
| Type | Single-use DMS |
| Delay | 10-18s adjustable (UDDT required) |

Thrust-to-weight: 1000N average, 5:1 minimum → max liftoff mass 20.4 kg. Very generous margin.

This flight validates the airframe under significantly higher loads and speeds before committing to the M-class cert flight.

### Flight #4: M1350W-PS Certification

The AeroTech M1350W-PS is the selected M-class motor for the L3 certification flight:

| Parameter | Value |
|---|---|
| Designation | M1350W |
| Diameter | 75mm (native — no adapter) |
| Length | 622mm |
| Total impulse | 5178 N-s (1% into M-class) |
| Average thrust | 1357 N |
| Max thrust | 1766 N |
| Burn time | 3.8 s |
| Total weight | 4808 g |
| Propellant | White Lightning |
| Type | Single-use DMS |
| Delay | **Plugged + Smoke** (no ejection charge) |

Thrust-to-weight: 1357N average, 5:1 minimum → max liftoff mass 27.7 kg. Very generous margin.

**Important notes**:

- "-PS" = Plugged + Smoke. No motor ejection charge — electronic deployment is the **only** recovery mechanism. No motor backup unlike L2 flight. This makes flight computer reliability critical.
- Requires L3 certification to purchase. Must be sourced through TAP members or prefect for the certification attempt.
- Barely into M-class (5178 N-s vs 5120 N-s M threshold) — keeps velocities and forces as low as possible while meeting the requirement.
- Built-in 3/8-16 threaded aluminum bulkhead for eye bolt attachment.

### Motor Adapter Strategy

The 75mm motor mount is the native size for the L3 cert flight. Smaller motors require centering adapters:

| Adapter | For Motors | Flights |
|---|---|---|
| 75mm → 38mm | J420R and other 38mm J motors | Flight #2 |
| 75mm → 54mm | L1000W and other 54mm L motors | Flight #3 |
| None (native 75mm) | M1350W-PS | Flight #4 (cert) |

Adapters can be 3D printed in PC CF or machined from phenolic/aluminum.

## Motor Selection

### Motor Type: Single-Use

Single-use (disposable casing) rather than reloadable, for several reasons:

- No need to purchase expensive reloadable casing hardware
- No borrowed equipment at risk in a CATO
- Simpler preparation on launch day
- Acceptable cost for a one-off certification flight

## Electronics

### Custom Flight Computer

A custom flight computer will be developed, based on the CATS Vega design but with improvements:

- **Improved power-up system**: Based on power management approach used for NASA Centennial Challenge robots — details TBD
- **Dual pyro channels**: For drogue and main deployment
- **Data logging**: Barometer, IMU, full flight telemetry
- Open source design, custom PCB

The custom flight computer will be validated on flights #2 and #3 before the L3 cert flight.

### Redundancy

For flights #2 and #3 (with delay-equipped motors): electronic dual deployment as primary, with motor delay charge as independent safety backup.

For flight #4 (M1350W-PS, plugged): **no motor backup available**. Recovery depends entirely on electronic deployment. This makes dual redundant electronics critical — consider flying two independent flight computers (primary + backup) for the cert flight.

## Airframe Design

### Minimum Dimensions

The 75mm motor mount sets the minimum body tube inner diameter. With typical wall thickness, this means a minimum airframe OD of approximately 80-85mm, though a larger airframe (e.g. 100-120mm) may be needed for stability, recovery hardware, and electronics bay space.

### Construction Approach

Scratch-built — all structural components designed and fabricated, not from a kit.

## Fin Can Design

### Design Tool: OpenSCAD

OpenSCAD chosen for fin can design because:

- C++-like syntax (familiar programming paradigm)
- Parametric design — dimensions driven by variables
- Direct export to 3MF for 3D printing
- Proven workflow from PeregrineFin and PeregrineFinCan75 projects

### 3D Printing: Bambu P1S

| Constraint | Value |
|---|---|
| Printer | Bambu P1S (standard, not Plus) |
| Max print height | 250mm (with AMS) |
| Max print area | 256 × 256 mm |

The 250mm height limit means the fin can body must be split into two or more rings that are bonded together. Fins are printed separately and bonded to the assembled can.

### Multi-Part Assembly Strategy

For a 75mm motor fin can:

1. **Fin can body**: Split into 2+ cylindrical rings (each ≤250mm tall), bonded together
2. **Fins**: Printed individually, bonded to assembled can
3. **Joints**: Designed with alignment features (pins, keys, or overlapping sections)

This avoids printing any single part that exceeds the printer's build volume.

### Material: Spectrum PC CF

Polycarbonate with carbon fiber fill, chosen after evaluating multiple materials:

| Property | PC CF Advantage |
|---|---|
| Temperature resistance | High — survives motor heat proximity |
| Toughness | High impact resistance |
| Cold weather | Does not become brittle (important for Swedish winter launches) |
| Stiffness | CF filler increases modulus, helps with fin flutter |
| Warping | CF filler reduces shrinkage anisotropy — the main problem with pure PC |

**Pure PC experience**: Printing large components from straight PC always produced some warping despite trying all common countermeasures (enclosure, bed adhesion, annealing, etc.). Spectrum PC CF largely solves this.

**Trade-off**: CF filler slightly reduces impact resistance compared to pure PC, but the increased stiffness is beneficial for flutter resistance.

**Printing notes**:

- Requires hardened steel nozzle (CF is abrasive)
- Print settings: 70% infill (consistent with PeregrineFinCan experience)
- Enclosure recommended (Bambu P1S has enclosure)

## Fin Flutter Analysis

### The Challenge

Fin flutter is the critical structural concern for L3. M-class motors produce significantly higher velocities than the J-class used for L2. Flutter occurs when aerodynamic forces couple with fin structural modes, and can destroy fins in milliseconds.

### Key Variables

- **Fin thickness**: Thicker = stiffer = higher flutter speed
- **Chord length**: Shorter chord helps
- **Span**: Shorter span helps (but reduces stability)
- **Material modulus**: Higher = better. PC CF is stiffer than pure PC
- **Airspeed**: Must analyze at maximum expected velocity (likely near burnout)

### Mitigation Strategies

1. **Material selection**: PC CF provides higher elastic modulus than most printable materials
2. **Carbon rod reinforcement**: Proven approach from PeregrineFin v0.7.0 (two 2.2mm channels at 25% and 60% chord). Same technique can scale to L3 fins
3. **Geometry optimization**: Shorter span, adequate thickness, appropriate taper ratio
4. **Conservative design**: Target flutter margin well above expected max velocity

### Previous Analysis Reference

PeregrineFin v0.7.0 analysis: span 137mm, area 23222mm², safety factor 1.65 at 10° AoA, flutter-safe to K-class motors with carbon rod reinforcement. L3 fin design must exceed this analysis for M-class speeds.

### Validation Through Flight Progression

The stepped flight approach (J → L → M) provides empirical validation of fin structural integrity at progressively higher speeds before the cert flight.

## Documentation Package

Tripoli L3 requires a comprehensive written project report. Planned sections:

- [ ] Project overview and objectives
- [ ] Stability analysis (CP/CG calculations, margin)
- [ ] Structural analysis (fin flutter, airframe loads)
- [ ] Recovery system design (dual deploy, redundancy)
- [ ] Electronics and avionics (custom flight computer design)
- [ ] Construction documentation with photos
- [ ] Ground testing results
- [ ] Flight simulation results
- [ ] Safety analysis
- [ ] L2 flight log (3 flights, demonstrating electronic deployment)

### Repository

This documentation will live in this repo initially. May move to a separate repository if the L3 project scope warrants it.

## Open Questions

1. ~~Specific 75mm single-use M motor selection for cert flight~~ → AeroTech M1350W-PS
2. Airframe material and diameter
3. Nose cone — 3D printed or purchased?
4. Custom flight computer detailed design
5. Second TAP member
6. Launch site — Enköping (SMRK) or elsewhere?
7. J420R weight budget — will L3 airframe stay under 8.56 kg for 5:1 T/W?
8. Dual redundant electronics for cert flight (plugged motor, no backup)?
9. Motor procurement logistics — M1350W-PS requires L3 cert to buy
10. Timeline

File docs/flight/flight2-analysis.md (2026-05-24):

# Flight #2 Analysis

Detailed analysis of CATS Vega telemetry from the L2 certification flight on 22 February 2026.

## Headline Results

| Parameter | Predicted (OpenRocket) | Actual (CATS Vega) |
|---|---|---|
| Apogee | 1100 m | **986.43 m** |
| Max velocity | — | **172.56 m/s** (≈ Mach 0.50) |
| Max acceleration | — | **171.63 m/s² (17.5 g)** |
| Burn time | ~2.0 s | **1.86 s** |
| Time to apogee | — | **12.67 s** |
| Total flight time | — | **102.07 s** (liftoff → touchdown) |

Apogee shortfall: **10.4 %** — much smaller than L1's 32 % shortfall.

## Flight Event Timeline (from FLIGHT_STATE records)

The CATS Vega writes a `FLIGHT_STATE` record every time the on-board FSM changes phase. These are the definitive event timestamps.

| Event | FSM transition | T+ (s) | Bootup ts (ms) | Altitude AGL | Velocity |
|---|---|---|---|---|---|
| Liftoff | → THRUSTING | 0.00 | 124510 | 0 m | 0 m/s |
| Burnout | → COASTING | 1.86 | 126370 | ~165 m | 172.56 m/s |
| Apogee / Drogue fired | → DROGUE | 12.98 | 137490 | 986.1 m | -2.9 m/s |
| Main charge fired | → MAIN | 76.62 | 201130 | 146.0 m | -14.3 m/s |
| Touchdown | → TOUCHDOWN | 102.07 | 226580 | -2.1 m | -0.5 m/s |

Liftoff time on launch day: **12:26:44 UTC** (from `st002.txt`).

## Telemetry Charts

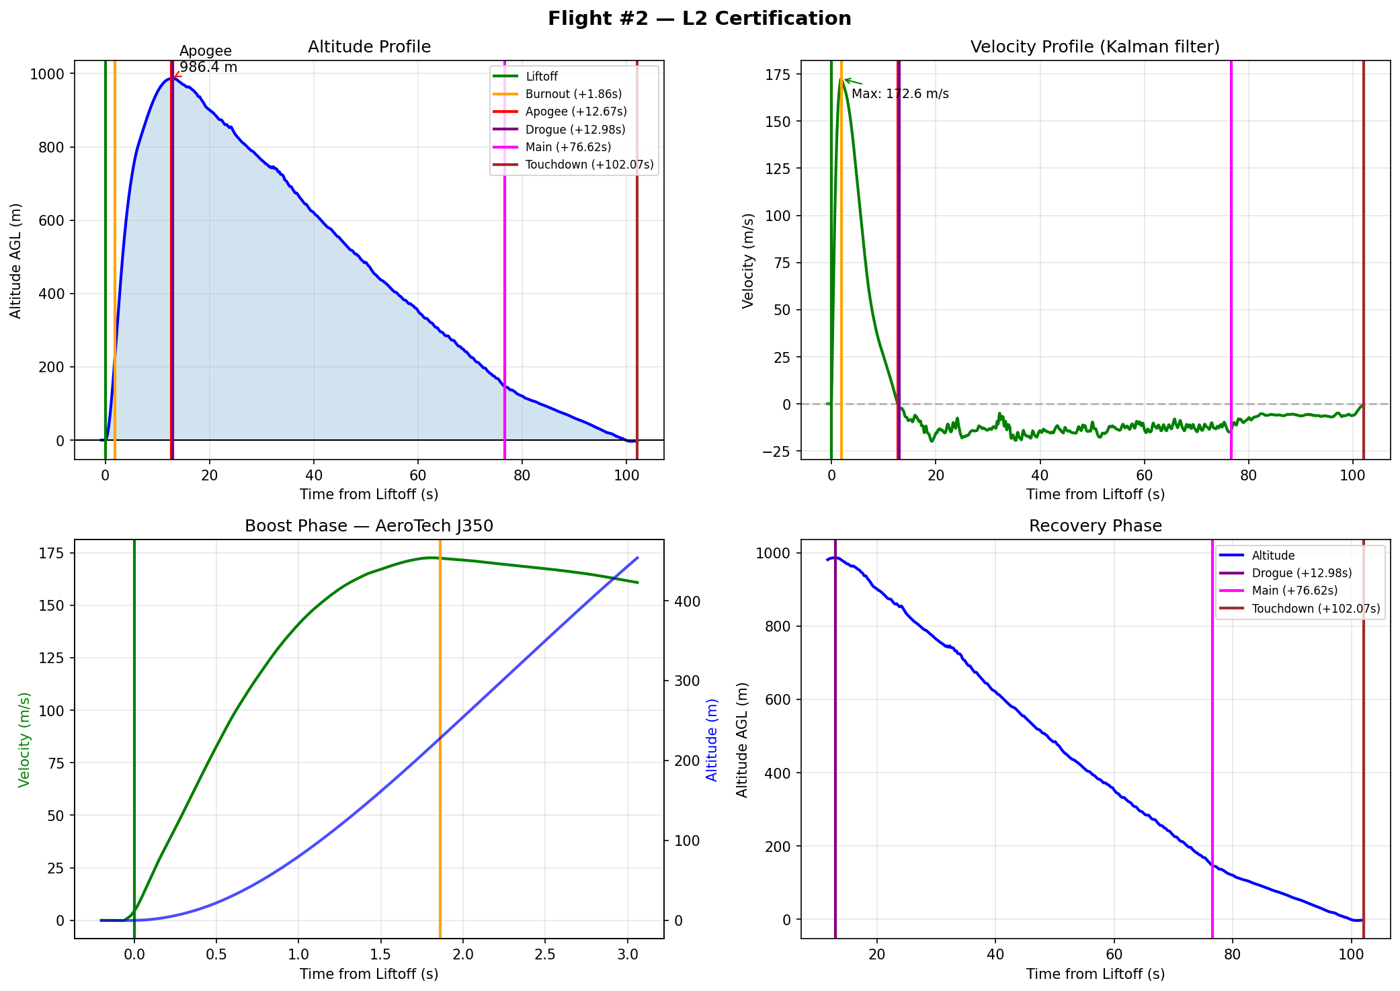
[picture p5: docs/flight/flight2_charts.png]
Flight #2 Telemetry


*Altitude, velocity, boost-phase detail, and recovery-phase detail.*

## Recovery System Performance

Dual deployment was mandatory for L2 because of the 500 m landing-radius rule (see [Certification](../certification/index.md#l2-certification-flight) for the rationale). The actual recovery profile:

| Phase | Duration | Avg descent rate | Notes |
|---|---|---|---|
| Under drogue (18") | 63.6 s | **13.17 m/s** (median 13.19) | Drogue descent from 986 m to 146 m |
| Under main (48") | 25.5 s | **6.34 m/s** (median 6.13) | Main from 146 m to ground |

The main charge fired at **146 m AGL** after the rocket descended through the configured **`main_altitude` = 150 m** threshold. The 4 m gap is the firmware's `MAIN_SAFETY_COUNTER = 30` hold: the FSM requires altitude < threshold for 30 consecutive 100 Hz samples (≈ 0.3 s) before transitioning to MAIN to reject barometer noise. At a ~13 m/s descent rate, the rocket dropped 4 m during the hold:

| Event | ts (ms) | Altitude | Note |
|---|---|---|---|
| First sample below threshold | 200810 | 149.94 m | `memory[0]` starts counting |
| `memory[0] > 30`, MAIN fired | 201130 | 145.94 m | 320 ms / 32 samples later |

The CATS Vega factory default `main_altitude` is 200 m (per `flight_computer/src/config/cats_config.cpp`); this rocket was configured to 150 m via the CATS Configurator. Touchdown velocity of 0.5 m/s indicates a clean, well-cushioned landing.

The drogue descent rate of ~13 m/s is in the expected range for a small drogue on a 3.1 kg rocket — the drogue's job is to keep the rocket vertical and prevent zipper, not to slow it significantly.

## Apogee Shortfall Analysis (10.4 %)

The actual 986 m vs predicted 1100 m gap is much smaller than L1's 32 % shortfall. Two factors:

### 1. Better-known launch mass

L1's main shortfall cause was unaccounted mass (two flight computers, batteries, etc.). For L2 the simulation input mass was 3100 g and the flight matched that mass — no surprise weight.

### 2. Old motor reload (likely small impulse loss)

The J350 was a ~25-year-old reload from Rolf Örell's stock (see [flight log](log.md#motor-story)). Nominal J350 specs: 720 Ns total impulse, ~2.0 s burn time. Measured: 1.86 s burn. Estimating the actual total impulse from rocket performance:

For a 3.1 kg rocket reaching 986 m apogee with max velocity 172.56 m/s, the kinetic + potential energy at burnout (≈ 165 m, 172.56 m/s) is:

$$
E_{burnout} = \tfrac{1}{2} m v^2 + m g h = \tfrac{1}{2}(3.1)(172.56)^2 + (3.1)(9.81)(165) \approx 46.1\ \text{kJ} + 5.0\ \text{kJ} \approx 51 \ \text{kJ}
$$

This is consistent with the motor delivering close to its rated impulse minus aerodynamic drag losses during the burn — within a few percent of nominal. The shortfall is not dominated by motor degradation; it is more plausibly a combination of:

- Small drag underestimate in the OpenRocket model
- Slightly lower-than-spec total impulse from the aged reload
- Sub-optimal launch angle (any wind weathercocking)

A drag coefficient sensitivity of just 5 % accounts for 30–50 m of altitude difference at this speed, which more than covers the 114 m gap.

### Temperature compensation gap

The MS5607 barometer-to-altitude conversion in firmware uses a hardcoded 15 °C reference temperature (same issue identified in [Flight #1 analysis](flight1-analysis.md#2-temperature-compensation-gap)). Launch day temperature was around 0 °C, giving roughly +5 % altitude overestimate. Temperature-corrected apogee is approximately **938 m**, making the true shortfall slightly larger (≈ 15 %).

## Comparison with Flight #1 (L1)

| Parameter | L1 (H128W) | L2 (J350) |
|---|---|---|
| Motor total impulse | 176 Ns | 720 Ns (≈4×) |
| Liftoff weight | 2350 g | 3100 g |
| Predicted apogee | 208 m | 1100 m |
| Actual apogee | 141.58 m | 986.43 m |
| Shortfall | 32 % | 10.4 % |
| Max velocity | 46.24 m/s | 172.56 m/s |
| Max acceleration | 4.5 g | 17.5 g |
| Burn time | 1.33 s | 1.86 s |
| Time to apogee | 5.68 s | 12.67 s |
| Recovery | Motor ejection | Dual electronic (drogue + main) |
| Total flight time | 26 s | 102 s |

The L2 flight is dramatically more energetic (≈10× kinetic energy at burnout) and the dual-deployment recovery worked as designed.

## Lessons for L3

1. **Trust FLIGHT_STATE records over velocity heuristics** — the on-board FSM transitions give exact, unambiguous event timestamps. Always use them for timeline analysis.
2. **Always download `stXXX.txt` alongside `flXXX.cfl`** — the stats file is the ground-truth cross-check.
3. **CATS configuration `main_altitude` is reliable** — main fired within metres of the configured value.
4. **Drogue descent rate of ~13 m/s is reasonable** for a 3 kg rocket on an 18" drogue; a larger L3 rocket may need more drogue area to keep descent under 20 m/s.

## Source Data

- Binary log: [`data/fl002.cfl`](data/fl002.cfl) (885 KB, 51,455 records parsed at 99.98 % coverage)
- Stats file: [`data/st002.txt`](data/st002.txt) (CATS Configurator export)
- Parsed summary: [`data/fl002.summary.json`](data/fl002.summary.json)
- Format reference: [`data/CATS_FORMAT.md`](data/CATS_FORMAT.md)
- Generator: [`data/generate_charts.py`](data/generate_charts.py)

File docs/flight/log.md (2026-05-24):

# Flight Log

## Flight Records

---

## Flight #2 - 2026-02-22 (L2 Certification)

### Conditions

| Parameter | Value |
|---|---|
| Location | Enköping, Sweden |
| Weather | Winter |
| Event | SMRK Launch Day |

### Configuration

| Parameter | Value |
|---|---|
| Motor | AeroTech J350 (~25-year-old reload from Rolf Örell) |
| Casing | 38/720 |
| Liftoff weight | 3100 g |
| CG location | 115 cm from nose tip |
| CP location | 130 cm from nose tip |
| Recovery mode | Dual deploy (electronic, CATS Vega) + motor backup |
| Drogue | 18" at apogee (electronic) |
| Main | 48" at lower altitude (electronic) |
| Motor delay | 14s factory (unmodified, backup safety charge) |

### Recovery Design

Dual deployment was required by the 500m landing radius constraint. Simulations showed that with main-only recovery from ~1000m, any wind above 4 m/s would carry the rocket beyond the allowed radius.

Triple-redundant ejection: two electronic black powder charges via CATS Vega (drogue at apogee, main at altitude), plus the motor's original 14s delay charge left unmodified as a safety backup.

### Flight Data

| Parameter | Predicted | Actual (CATS Vega) |
|---|---|---|
| Apogee | 1100 m | **986.43 m** |
| Max velocity | — | **172.56 m/s** (≈ Mach 0.50) |
| Max acceleration | — | **17.5 g** |
| Burn time | ~2.0 s | 1.86 s |
| Time to apogee | — | 12.67 s |
| Total flight time | — | 102.07 s |
| Liftoff UTC | — | 12:26:44 |

Flight data downloaded from CATS Vega (file: `fl002.cfl`). See [Flight #2 Analysis](flight2-analysis.md) for full telemetry, FSM event timeline, and recovery system performance.

### Results

- [x] Successful launch
- [x] Stable flight
- [x] Dual deployment worked (drogue at apogee, main at 146 m AGL)
- [x] Touchdown velocity 0.5 m/s — clean landing
- [x] Recovered intact
- [x] **L2 CERTIFICATION ACHIEVED**

### Motor Story

Originally ordered an AeroTech J420R-14A from Space Rocket Technology (Germany). DHL shipping label created 4 February but the package was never picked up — no tracking movement after three weeks. Rolf Örell had some ~25-year-old AeroTech J350 reloads in stock and offered one. It worked perfectly.

### Certification

| Field | Value |
|---|---|
| Certification | Tripoli L2 |
| Certifying Authority | Rolf Örell (TRA# 3728) |
| Flyer | Tõnu Samuel (TRA# 38105) |

### Flight Video

See [L2 Certification](../certification/index.md#l2-certification-flight) for video.

---

## Flight #1 - 2026-01-24 (L1 Certification)

### Conditions

| Parameter | Value |
|---|---|
| Location | Enköping, Sweden |
| Weather | Winter, snow on ground, -5°C |
| Event | SMRK Launch Day |

### Configuration

| Parameter | Value |
|---|---|
| Motor | AeroTech H128W-14A |
| Liftoff weight | 2350 g |
| CG location | 115 cm from nose tip |
| CP location | 130 cm from nose tip |
| Stability | ~1.5 calibers |
| Recovery mode | Single deploy (motor ejection) |
| Delay | ~8s intended (14s factory - 8s drilled + 2s disk) |

### Flight Data

| Parameter | Predicted | Actual (CATS) |
|---|---|---|
| Apogee | 208 m | 141.58 m |
| Burnout velocity | — | 45.69 m/s |
| Burnout altitude | — | 39.84 m |
| Burn time | 1.4 s | 1.33 s |
| Time to apogee | 6.0 s | 5.68 s |
| Motor delay | 8.0 s | 9.47 s |
| Deployment after apogee | — | 5.12 s |

Altitude recorded by CATS Vega flight computer (file: fl001.cfl).

### Results

- [x] Successful launch
- [x] Stable flight
- [x] Recovery deployed
- [x] Recovered intact
- [x] **L1 CERTIFICATION ACHIEVED**

### Analysis Summary

The 32% altitude shortfall (208m predicted → 141.58m actual) has three identified causes:

1. **Mass discrepancy (primary)**: Burnout velocity of 45.69 m/s at 39.84m gives theoretical max of ~146m (no drag). Reaching 208m would require ~58-60 m/s burnout velocity, indicating rocket was heavier than simulated.

2. **Temperature compensation gap**: MS5607 barometer uses hardcoded 15°C in altitude formula, but flight was at -5°C. This causes +7.5% altitude overestimate (~10m). True apogee approximately 132m.

3. **Venting lag**: No venting holes in rocket body. Evidence: altitude plateau at apogee (141.4-141.6m for ~1 second), pressure oscillation 100680-100730 Pa for 1.5s. Ascent velocities appear artificially low with only 4.6m apparent drag loss vs expected 15-25m.

See [Flight #1 Analysis](flight1-analysis.md) for detailed telemetry and recommendations.

### Certification

| Field | Value |
|---|---|
| Certification | Tripoli L1 |
| Certifying Authority | Rolf Örell (TRA# 3728) |
| Flyer | Tõnu Samuel (TRA# 38105) |

### Photos

Launch photo and recovery photo with Liza holding "SIPSIK" rocket - see certification documentation.

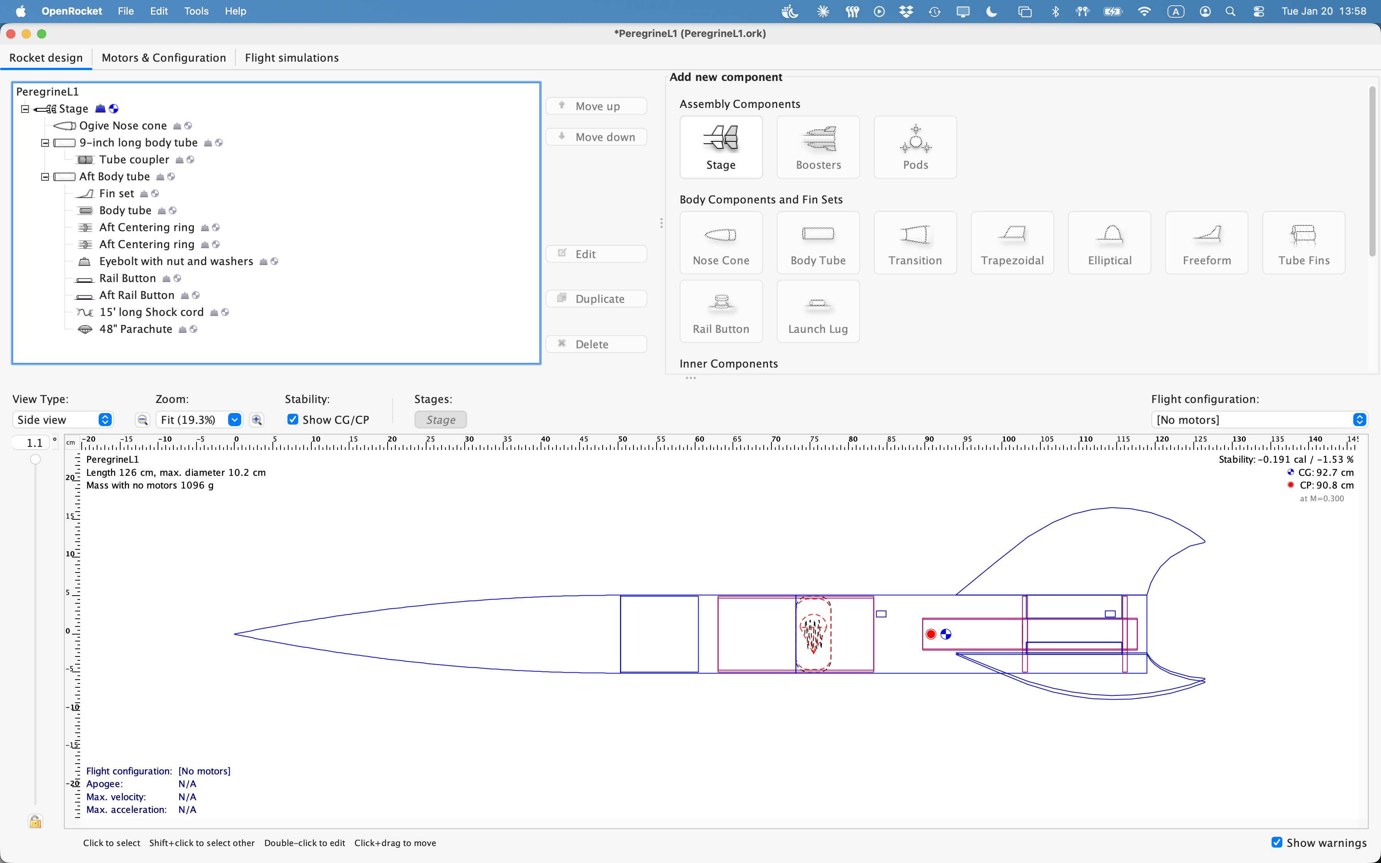
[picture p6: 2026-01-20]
docs/photos/Screenshot 2026-01-20 at 13.58.26.png

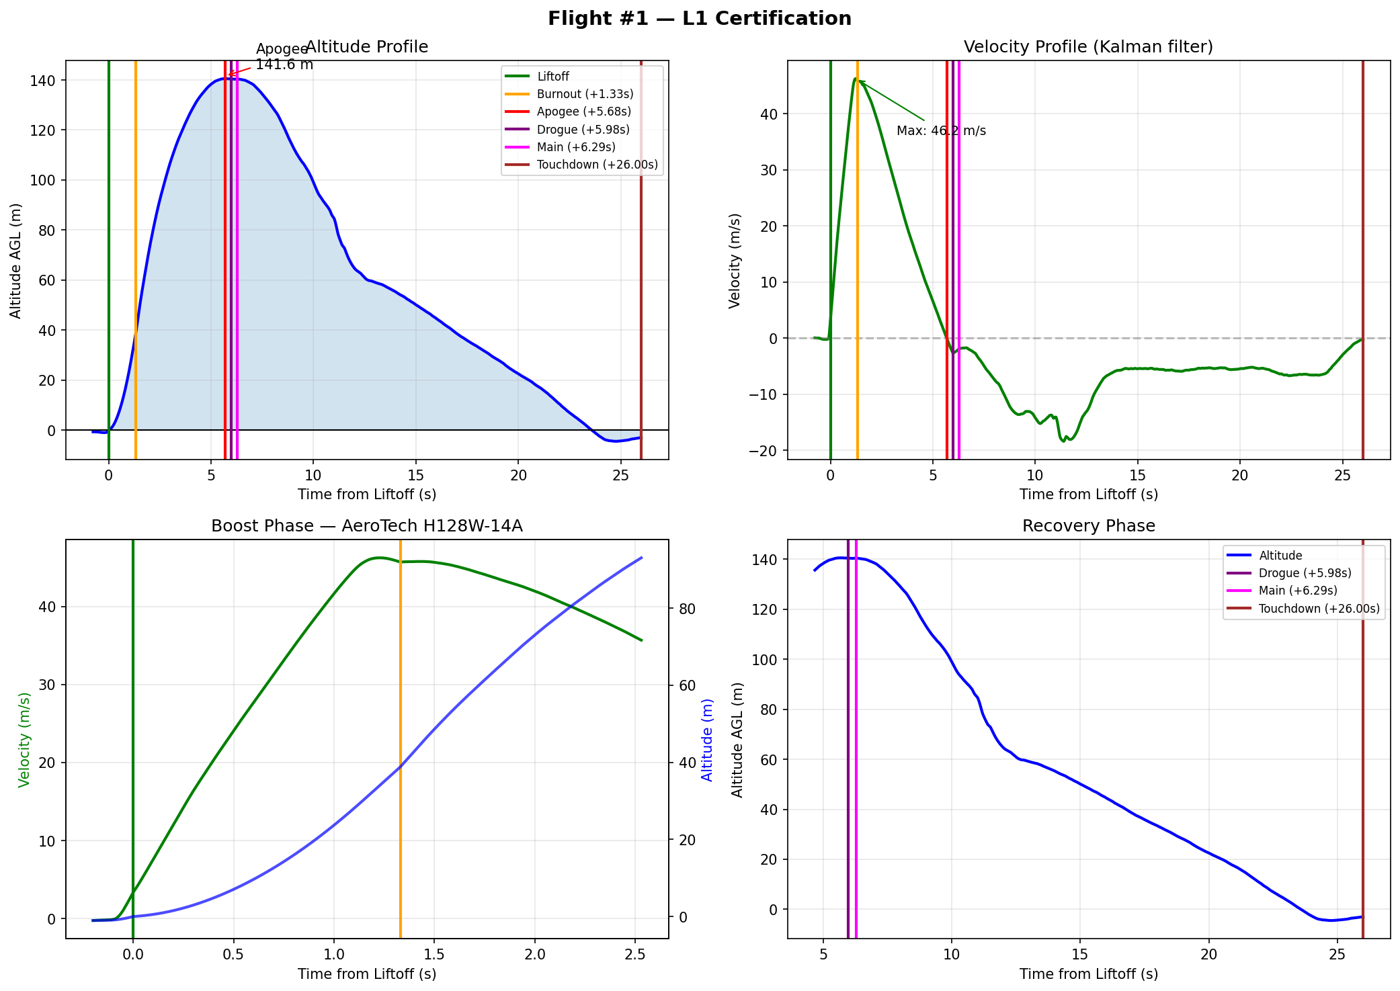
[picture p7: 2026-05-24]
docs/flight/flight1_charts.png

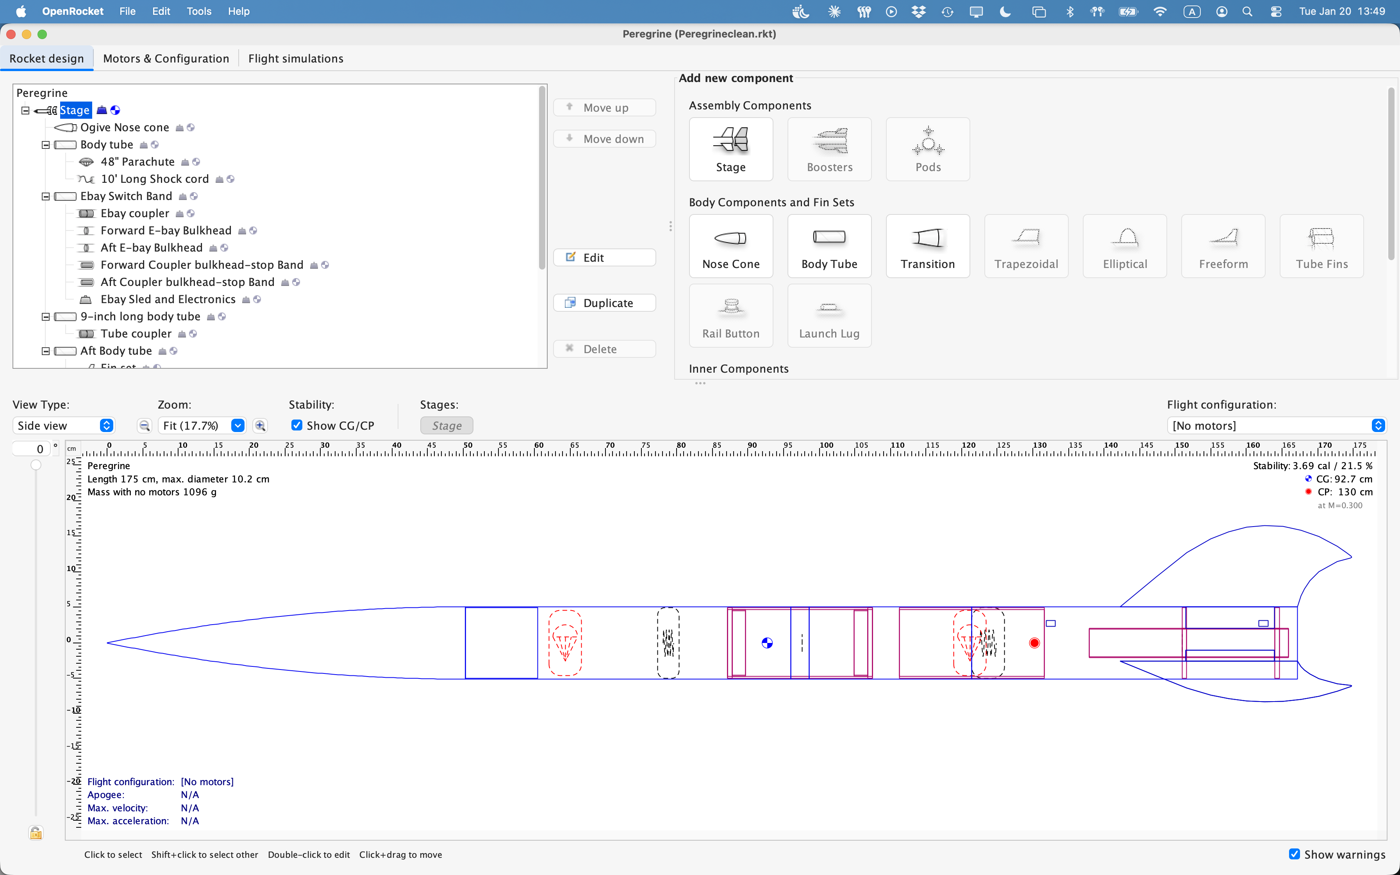
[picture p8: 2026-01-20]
docs/photos/Screenshot 2026-01-20 at 13.49.56.png

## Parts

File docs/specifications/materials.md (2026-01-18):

# Materials

## Airframe Materials

### Body Tubes

| Property | Value |
|---|---|
| Material | Kraft paper |
| Wall Type | Heavy wall |
| Surface | White glassine overwrap |
| Spiral | Tight wound |

**Characteristics:**

- Easy to mark with pencil
- Tight spirals minimize filling work
- White surface shows construction marks clearly
- Can be reinforced with fiberglass if desired

### Centering Rings & Bulkheads

| Property | Value |
|---|---|
| Material | Aviation plywood |
| Cut Method | Laser cut |
| Finish | Requires light sanding on edges |

### Fins

| Property | Value |
|---|---|
| Material | Aeronautical birch plywood |
| Cut Method | Laser cut |
| Profile | Swept-back curved |
| Grain | Oriented for maximum strength |

## Nose Cone Material

| Property | Value |
|---|---|
| Material | Polypropylene plastic |
| Flexibility | Moderate flex (impact resistant) |
| Paint Adhesion | Requires adhesion promoter |

!!! warning "Painting Polypropylene"
    Polypropylene does not accept paint well. Use:
    
    1. Clean surface thoroughly
    2. Apply adhesion promoter (plastic primer)
    3. Apply regular primer
    4. Paint as normal

## Recovery Materials

### Parachutes

| Property | Value |
|---|---|
| Material | Thin-mill ripstop nylon |
| Feel | Soft, silk-like |
| Shroud Lines | Double-looped at canopy |
| Packing | Very compact |

### Shock Cord

| Property | Value |
|---|---|
| Type | Tubular nylon |
| Color | Fluorescent orange |
| Visibility | High (aids recovery) |

### Chute Protectors

| Property | Value |
|---|---|
| Material | Nomex cloth |
| Size | 12" diameter |
| Quantity | 2 (one per bay) |
| Reusability | Fully reusable |

## Recommended Construction Adhesives

| Application | Recommended |
|---|---|
| General Assembly | 5-minute epoxy |
| Fin Fillets | 30-minute epoxy or Rocketpoxy |
| High-Stress Joints | JB Weld or 30-minute epoxy |
| Motor Retainer | High-temperature epoxy (JB Weld) |
| Quick Tacks | Thick CA (cyanoacrylate) |

## Material Strengths

!!! note "Construction Philosophy"
    The Peregrine uses traditional rocketry materials:
    
    - Proven reliability
    - Easy to work with
    - Familiar to most builders
    - Good strength-to-weight ratio
    - Economical
    
    For extreme applications, tubes can be reinforced with fiberglass cloth.

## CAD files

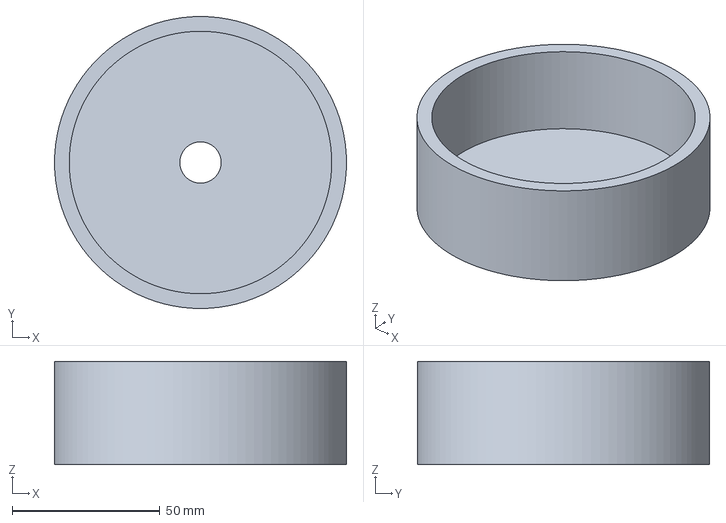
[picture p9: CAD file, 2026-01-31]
openscad/EjectionPiston.3mf
98.9 x 98.9 x 35.0 mm

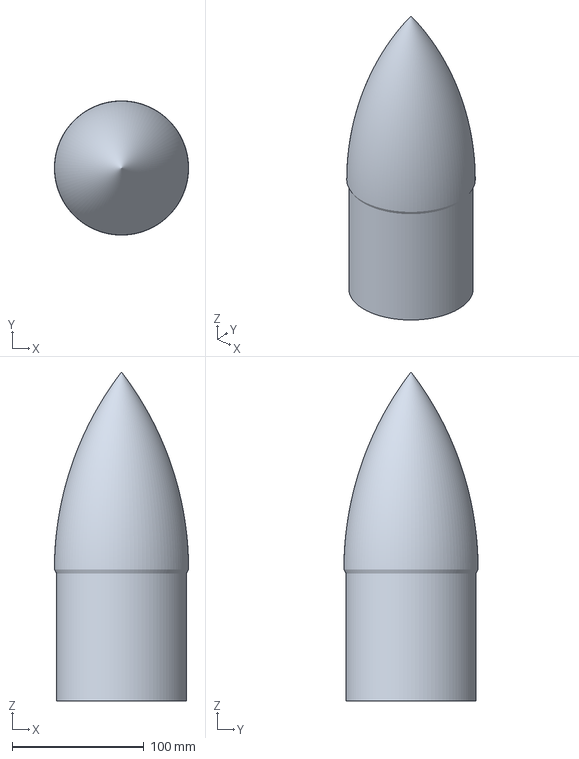
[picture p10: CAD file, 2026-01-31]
openscad/PeregrineNoseConeElectronics.3mf
102.0 x 102.0 x 250.0 mm

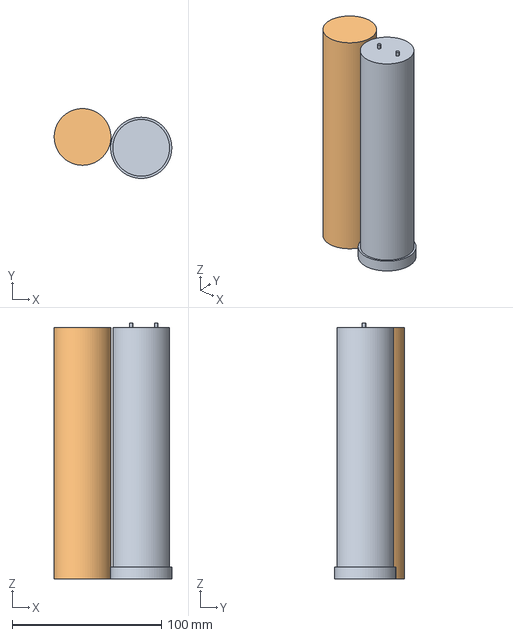
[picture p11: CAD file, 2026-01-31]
openscad/J420R.3mf
78.8 x 46.8 x 171.5 mm
OpenSCAD Model_1_B
OpenSCAD Model_1_A

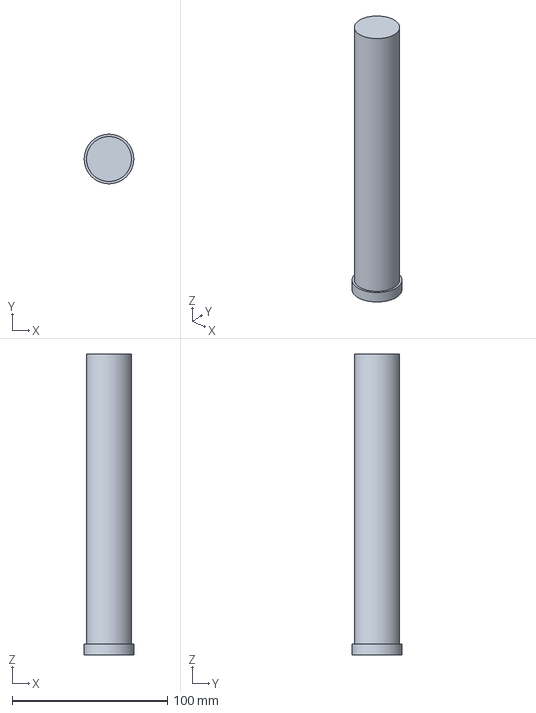
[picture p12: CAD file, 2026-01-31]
openscad/H128W.3mf
32.0 x 32.0 x 194.0 mm

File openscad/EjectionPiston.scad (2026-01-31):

// Peregrine L1 Ejection Piston
// Piston-style ejection system to protect parachute from hot gases
//
// The piston sits between the motor bay and recovery bay.
// Ejection gases push the piston, which pushes the parachute out.
// Shock cord passes through center hole, retaining the piston.
//
// RETENTION: Shock cord knot/washer below piston (standard practice)
// No external lip - that design was flawed (wouldn't fit in tube)
//
// Author: Generated for Tõnu's L1 Certification Project
// License: MIT

/* [Body Tube Dimensions] */
// Body tube inner diameter (mm) - piston slides inside this
body_tube_id = 99.1;

// Clearance between piston and tube wall (mm per side)
// Too tight = sticks, too loose = gas blows past
piston_clearance = 0.1;

/* [Piston Dimensions] */
// Total piston height (mm)
piston_height = 35;

// Cup cavity depth (mm) - deeper = more gas capture
cup_depth = 20;

// Cup wall thickness (mm)
cup_wall = 5.0;

// Base thickness below cup (mm)
base_thickness = 5;

/* [Shock Cord Retention] */
// Center hole diameter for shock cord (mm)
// Typical tubular nylon: 8-12mm, add clearance
cord_hole_dia = 14;

// Cord hole reinforcement thickness (mm)
cord_reinforce = 2;

// Cord hole reinforcement height above base (mm)
cord_reinforce_height = 10;

// Retention washer recess (for washer + knot below piston)
washer_recess = true;

// Washer outer diameter (mm) - e.g., M8 fender washer = 24mm
washer_od = 24;

// Washer recess depth (mm)
washer_recess_depth = 2;

/* [Vent Holes] */
// Include vent holes (REQUIRED - prevents vacuum lock during descent)
include_vents = false;

// Number of vent holes
vent_count = 6;

// Vent hole diameter (mm)
vent_dia = 5;

// Vent hole distance from center (mm)
vent_radius = 30;

/* [O-Ring Seal (Optional)] */
// Include O-ring groove for better gas seal
include_oring = true;

// O-ring cross-section diameter (mm) - standard 3mm
oring_dia = 3;

// O-ring groove depth (mm)
oring_groove_depth = 1.5;

// O-ring position from piston top (mm)
oring_position = 10;

/* [Print Settings] */
// Resolution
$fn = 100;

/* [Calculated Values] */
// Piston outer diameter
piston_od = body_tube_id - (2 * piston_clearance);

// Piston radius
piston_r = piston_od / 2;

// Cup inner diameter
cup_id = piston_od - (2 * cup_wall);

// Cup inner radius
cup_ir = cup_id / 2;

// ============================================
// Modules
// ============================================

// Main piston body (cylinder)
module piston_body() {
    cylinder(h = piston_height, r = piston_r, $fn = $fn);
}

// Cup cavity (hollows out the top - GAS SIDE)
// This captures ejection gas pressure
module cup_cavity() {
    translate([0, 0, base_thickness])
    cylinder(h = cup_depth + 11, r = cup_ir, $fn = $fn);
}

// Center hole for shock cord
module cord_hole() {
    translate([0, 0, -1])
    cylinder(h = piston_height + 2, d = cord_hole_dia, $fn = 64);
}

// Reinforcement ring around cord hole (inside cup)
module cord_reinforcement() {
    translate([0, 0, base_thickness])
    difference() {
        cylinder(h = cord_reinforce_height, d = cord_hole_dia + (2 * cord_reinforce), $fn = 64);
        translate([0, 0, -1])
        cylinder(h = cord_reinforce_height + 2, d = cord_hole_dia, $fn = 64);
    }
}

// Washer recess on bottom (PARACHUTE SIDE)
// Allows washer+knot to sit flush, retaining piston on cord
module washer_recess() {
    translate([0, 0, -0.01])
    cylinder(h = washer_recess_depth + 0.01, d = washer_od, $fn = 64);
}

// Vent holes through the base
// PURPOSE: Allow air to flow through during descent
// Without vents, vacuum forms behind piston, trapping parachute
module vent_holes() {
    for (i = [0 : vent_count - 1]) {
        angle = i * (360 / vent_count);
        rotate([0, 0, angle])
        translate([vent_radius, 0, -1])
        cylinder(h = base_thickness + 2, d = vent_dia, $fn = 32);
    }
}

// O-ring groove on outer surface (optional, for better gas seal)
module oring_groove() {
    translate([0, 0, piston_height - oring_position])
    rotate_extrude($fn = $fn)
    translate([piston_r - oring_groove_depth, 0, 0])
    circle(d = oring_dia, $fn = 32);
}

// Complete piston assembly
module ejection_piston() {
    difference() {
        union() {
            // Main body
            piston_body();
            
            // Cord hole reinforcement
            cord_reinforcement();
        }
        
        // Subtract cup cavity (gas side)
        cup_cavity();
        
        // Subtract cord hole
        cord_hole();
        
        // Subtract vent holes
        if (include_vents) {
            vent_holes();
        }
        
        // Subtract washer recess (parachute side)
        if (washer_recess) {
            washer_recess();
        }
        
        // Subtract O-ring groove
        if (include_oring) {
            oring_groove();
        }
    }
}

// ============================================
// Render
// ============================================

ejection_piston();

// ============================================
// Info Echo
// ============================================

echo("=== Ejection Piston Parameters ===");
echo(str("Body tube ID: ", body_tube_id, " mm"));
echo(str("Piston OD: ", piston_od, " mm"));
echo(str("Piston clearance: ", piston_clearance, " mm per side"));
echo(str("Total height: ", piston_height, " mm"));
echo(str("Cup depth: ", cup_depth, " mm"));
echo(str("Cup ID: ", cup_id, " mm"));
echo(str("Cord hole: ", cord_hole_dia, " mm"));
echo(str("Vent holes: ", include_vents ? str(vent_count, " x ", vent_dia, " mm") : "DISABLED (not recommended!)"));

// Volume estimate for pressure calculation
cup_volume_cm3 = PI * pow(cup_ir/10, 2) * (cup_depth/10);
echo(str("Cup volume: ~", cup_volume_cm3, " cm³"));

// Weight estimate (PETG ~1.27 g/cm³)
piston_vol = PI * pow(piston_r/10, 2) * (piston_height/10);
cup_vol = PI * pow(cup_ir/10, 2) * (cup_depth/10);
cord_vol = PI * pow((cord_hole_dia/2)/10, 2) * (piston_height/10);
approx_vol = piston_vol - cup_vol - cord_vol;
approx_weight = approx_vol * 1.27;
echo(str("Approx weight (PETG): ~", approx_weight, " g"));

echo("");
echo("=== HOW IT WORKS ===");
echo("1. Piston sits in body tube, cup facing MOTOR (aft)");
echo("2. Shock cord passes through center hole");
echo("3. Washer + knot BELOW piston retains it on cord");
echo("4. Parachute sits ABOVE piston (forward)");
echo("");
echo("EJECTION:");
echo("  - Motor charge fires, gas fills cup cavity");
echo("  - Pressure pushes piston forward");
echo("  - Piston pushes parachute out");
echo("  - Parachute NEVER touches hot gas!");
echo("");
echo("DESCENT (why vents matter):");
echo("  - Rocket falls, air rushes past");
echo("  - Without vents: vacuum forms behind piston");
echo("  - Vacuum holds piston in tube = parachute trapped!");
echo("  - WITH vents: air flows through, piston falls freely");
echo("");
echo("=== Assembly Notes ===");
echo("1. Print with PETG for heat resistance");
echo("2. Orient cup-side UP on print bed (base down)");
echo("3. Thread shock cord through center hole");
echo("4. Add fender washer (M8, 24mm OD) below piston");
echo("5. Tie figure-8 knot below washer");
echo("6. Test slide fit - should move freely with light resistance");

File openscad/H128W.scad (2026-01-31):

// Aerotech H128W-14A Motor Mass Equivalent Model
// Solid PLA with steel rod cavity and retainer shoulder

// === MOTOR SPECIFICATIONS ===
motor_diameter = 29;      // mm
motor_length = 194;       // mm
motor_mass = 206;         // grams

// === AFT CLOSURE SHOULDER ===
shoulder_diameter = 32;   // mm (retainer catches this)
shoulder_thickness = 7;   // mm

// === MATERIAL DENSITIES ===
pla_density = 1.24;       // g/cm³
steel_density = 7.85;     // g/cm³

// === STEEL ROD PARAMETERS ===
rod_diameter = 8;         // mm
rod_clearance = 0.3;      // mm

// === CALCULATIONS ===
motor_radius = motor_diameter / 2;
shoulder_radius = shoulder_diameter / 2;
rod_radius = rod_diameter / 2;
cavity_radius = rod_radius + rod_clearance;

// Body length (excluding shoulder)
body_length = motor_length - shoulder_thickness;

// Volumes (cm³)
body_volume_mm3 = PI * pow(motor_radius, 2) * body_length;
shoulder_volume_mm3 = PI * pow(shoulder_radius, 2) * shoulder_thickness;
solid_volume_cm3 = (body_volume_mm3 + shoulder_volume_mm3) / 1000;

pla_mass_if_solid = solid_volume_cm3 * pla_density;
mass_deficit = motor_mass - pla_mass_if_solid;

// Required steel rod
steel_volume_needed_cm3 = mass_deficit / steel_density;
rod_length_needed = (steel_volume_needed_cm3 * 1000) / (PI * pow(rod_radius, 2));

// Cavity positioning (centered in body, avoiding shoulder)
cavity_length = ceil(rod_length_needed) + 2;
cavity_offset = shoulder_thickness + (body_length - cavity_length) / 2;

// Final mass calculation
cavity_volume_cm3 = (PI * pow(cavity_radius, 2) * cavity_length) / 1000;
pla_volume_cm3 = solid_volume_cm3 - cavity_volume_cm3;
pla_mass = pla_volume_cm3 * pla_density;
rod_volume_cm3 = (PI * pow(rod_radius, 2) * rod_length_needed) / 1000;
rod_mass = rod_volume_cm3 * steel_density;
total_mass = pla_mass + rod_mass;

// === CONSOLE OUTPUT ===
echo("========================================");
echo("  AEROTECH H128W-14A MASS EQUIVALENT");
echo("========================================");
echo(str("Target mass: ", motor_mass, " g"));
echo(str("Body length: ", body_length, " mm"));
echo(str("Shoulder: ", shoulder_diameter, "mm x ", shoulder_thickness, "mm"));
echo("----------------------------------------");
echo(str("Steel rod: ", rod_diameter, "mm x ", rod_length_needed, "mm"));
echo(str("Cut rod to: ", ceil(rod_length_needed), " mm"));
echo("----------------------------------------");
echo(str("PLA mass: ", pla_mass, " g"));
echo(str("Steel mass: ", rod_mass, " g"));
echo(str("TOTAL MASS: ", total_mass, " g"));
echo(str("Target: ", motor_mass, " g (error: ", total_mass - motor_mass, " g)"));
echo("========================================");

// === NOZZLE COSMETIC DETAIL ===
nozzle_exit_diameter = 10;
nozzle_depth = 5;

// === MODEL ===
module motor_with_shoulder() {
    difference() {
        union() {
            // Aft shoulder (at z=0, this is the aft/nozzle end)
            cylinder(h = shoulder_thickness, r = shoulder_radius, $fn = 72);
            
            // Main body
            translate([0, 0, shoulder_thickness])
                cylinder(h = body_length, r = motor_radius, $fn = 72);
        }
        
        // Rod cavity
        translate([0, 0, cavity_offset])
            cylinder(h = cavity_length + 0.1, r = cavity_radius, $fn = 48);
        
        // Nozzle detail (aft end)
        translate([0, 0, -0.1])
            cylinder(h = nozzle_depth + 0.1, 
                    r1 = nozzle_exit_diameter/2, 
                    r2 = nozzle_exit_diameter * 0.35, 
                    $fn = 48);
    }
}

motor_with_shoulder();

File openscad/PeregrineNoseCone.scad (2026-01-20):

// Peregrine L1 Nose Cone
// Parametric ogive nose cone for Apogee Peregrine
// Designed to fit body tube ID 99.1mm, OD 102mm
// 
// Author: Generated for Tõnu's L1 Certification Project
// License: MIT

/* [Main Dimensions] */
// Body tube outer diameter (mm)
body_tube_od = 102;

// Body tube inner diameter (mm)
body_tube_id = 99.1;

// Nose cone length (mm) - typically 3-5 calibers
// 150mm = 1.5 calibers (blunter, more drag, slower flight)
// 300mm = 3 calibers (standard ogive)
// For P1S single-piece print: max ~150mm nose + 100mm shoulder = 250mm
nose_length = 150;

// Shoulder length (mm) - typically 1-1.5 calibers
shoulder_length = 100;

/* [Wall and Fit] */
// Wall thickness (mm)
wall_thickness = 2.5;

// Shoulder clearance (mm) - gap for easy fit into tube
shoulder_clearance = 0.6;

// Shoulder wall thickness (mm)
shoulder_wall = 2.0;

/* [Nose Cone Shape] */
// Shape: 0=Ogive, 1=Conical, 2=Elliptical, 3=Parabolic
shape_type = 0; // [0:Ogive, 1:Conical, 2:Elliptical, 3:Parabolic]

// Ogive shape factor (1.0 = tangent ogive, higher = more blunt)
ogive_factor = 1.0;

/* [Ballast and Hardware] */
// Include ballast cavity
include_ballast_cavity = true;

// Ballast cavity diameter (mm)
ballast_cavity_dia = 30;

// Ballast cavity depth from shoulder end (mm)
ballast_cavity_depth = 80;

/* [Print Settings] */
// Resolution (higher = smoother but slower)
$fn = 100;

// Split into two parts for printing
split_for_printing = false;

// Split position from base (mm) - only used if split_for_printing=true
split_position = 125;

// Joint overlap (mm)
joint_overlap = 15;

// Joint clearance (mm)
joint_clearance = 0.3;

/* [Calculated Values] */
// Base radius (outer)
base_radius = body_tube_od / 2;

// Shoulder outer radius (fits inside body tube)
shoulder_radius = (body_tube_id - shoulder_clearance) / 2;

// Ogive radius (for tangent ogive calculation)
ogive_radius = (base_radius * base_radius + nose_length * nose_length) / (2 * base_radius);

// ============================================
// Nose Cone Profile Functions
// ============================================

// Tangent Ogive profile
function ogive_radius_at(x) = 
    let(rho = ogive_radius * ogive_factor)
    sqrt(rho * rho - (nose_length - x) * (nose_length - x)) - rho + base_radius;

// Conical profile
function conical_radius_at(x) = base_radius * x / nose_length;

// Elliptical profile  
function elliptical_radius_at(x) = base_radius * sqrt(1 - ((nose_length - x) / nose_length) * ((nose_length - x) / nose_length));

// Parabolic profile
function parabolic_radius_at(x) = base_radius * sqrt(x / nose_length);

// Select profile based on shape_type
function profile_radius_at(x) = 
    shape_type == 0 ? ogive_radius_at(x) :
    shape_type == 1 ? conical_radius_at(x) :
    shape_type == 2 ? elliptical_radius_at(x) :
    parabolic_radius_at(x);

// ============================================
// Modules
// ============================================

// Generate nose cone outer shell as rotational solid
module nose_cone_outer() {
    step = nose_length / $fn;
    
    rotate_extrude(angle = 360, $fn = $fn) {
        polygon(points = concat(
            [[0, 0]],
            [for (x = [step : step : nose_length]) 
                [profile_radius_at(x), x]],
            [[base_radius, nose_length]],
            [[0, nose_length]]
        ));
    }
}

// Generate nose cone inner cavity
module nose_cone_inner() {
    step = nose_length / $fn;
    tip_solid = 20; // Solid tip region
    
    rotate_extrude(angle = 360, $fn = $fn) {
        polygon(points = concat(
            [[0, tip_solid]],
            [for (x = [tip_solid + step : step : nose_length]) 
                [max(0, profile_radius_at(x) - wall_thickness), x]],
            [[base_radius - wall_thickness, nose_length]],
            [[0, nose_length]]
        ));
    }
}

// Shoulder (slides into body tube)
module shoulder() {
    translate([0, 0, nose_length])
    difference() {
        cylinder(h = shoulder_length, r = shoulder_radius, $fn = $fn);
        
        // Hollow inside
        translate([0, 0, -1])
        cylinder(h = shoulder_length + 2, r = shoulder_radius - shoulder_wall, $fn = $fn);
    }
}

// Ballast cavity (accessible from shoulder end)
module ballast_cavity() {
    translate([0, 0, nose_length + shoulder_length - ballast_cavity_depth])
    cylinder(h = ballast_cavity_depth + 1, d = ballast_cavity_dia, $fn = 64);
}

// Complete nose cone
module complete_nose_cone() {
    difference() {
        union() {
            // Main nose cone shape
            difference() {
                nose_cone_outer();
                nose_cone_inner();
            }
            
            // Shoulder
            shoulder();
        }
        
        // Ballast cavity
        if (include_ballast_cavity) {
            ballast_cavity();
        }
    }
}

// Split joint - female (socket)
module joint_female() {
    cylinder(h = joint_overlap, r = base_radius - wall_thickness + joint_clearance, $fn = $fn);
}

// Split joint - male (plug)
module joint_male() {
    cylinder(h = joint_overlap, r = base_radius - wall_thickness, $fn = $fn);
}

// Lower section (tip to split)
module lower_section() {
    difference() {
        intersection() {
            complete_nose_cone();
            cylinder(h = split_position, r = base_radius + 1, $fn = $fn);
        }
        
        // Female joint socket at top
        translate([0, 0, split_position - joint_overlap])
        joint_female();
    }
}

// Upper section (split to shoulder)
module upper_section() {
    difference() {
        complete_nose_cone();
        
        // Remove lower section
        cylinder(h = split_position - joint_overlap, r = base_radius + 1, $fn = $fn);
    }
    
    // Male joint plug
    translate([0, 0, split_position - joint_overlap])
    difference() {
        joint_male();
        
        // Keep it hollow
        translate([0, 0, -1])
        cylinder(h = joint_overlap + 2, r = base_radius - wall_thickness - shoulder_wall, $fn = $fn);
    }
}

// ============================================
// Render
// ============================================

if (split_for_printing) {
    // Show both parts side by side
    translate([-base_radius - 10, 0, 0])
    lower_section();
    
    translate([base_radius + 10, 0, 0])
    upper_section();
} else {
    // Complete nose cone
    complete_nose_cone();
}

// ============================================
// Info Echo
// ============================================

echo("=== Peregrine Nose Cone Parameters ===");
echo(str("Body tube OD: ", body_tube_od, " mm"));
echo(str("Body tube ID: ", body_tube_id, " mm"));
echo(str("Shoulder OD: ", shoulder_radius * 2, " mm"));
echo(str("Nose length: ", nose_length, " mm"));
echo(str("Shoulder length: ", shoulder_length, " mm"));
echo(str("Total length: ", nose_length + shoulder_length, " mm"));
echo(str("Wall thickness: ", wall_thickness, " mm"));
echo(str("Shape: ", shape_type == 0 ? "Ogive" : shape_type == 1 ? "Conical" : shape_type == 2 ? "Elliptical" : "Parabolic"));

if (include_ballast_cavity) {
    // Approximate ballast volume in cm³
    ballast_vol = PI * pow(ballast_cavity_dia/2, 2) * ballast_cavity_depth / 1000;
    echo(str("Ballast cavity volume: ", ballast_vol, " cm³"));
    echo(str("Lead shot capacity: ~", ballast_vol * 7.0, " g"));
    echo(str("Steel shot capacity: ~", ballast_vol * 4.8, " g"));
}

echo(str("Fits Bambu P1S (256mm): ", nose_length + shoulder_length <= 256 ? "YES" : "NO - use split_for_printing=true"));

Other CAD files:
openscad/J420R.scad
openscad/PeregrineNoseConeElectronics.scad

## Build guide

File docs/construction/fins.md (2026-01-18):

# Fin Construction

## Fin Specifications

| Property | Value |
|---|---|
| Quantity | 3 |
| Material | Birch plywood |
| Profile | Swept-back curved |
| Attachment | Through-the-wall (TTW) |
| Extends Below Tube | Yes |

## Unique Fin Design

The Peregrine's fins are distinctive:

- Curved leading edge (reminiscent of 1950s sci-fi rockets)
- Extend below the body tube base
- Interlocking tab structure for alignment
- Large surface area for stability

## 6-Point Attachment Method

The fins use **Through-The-Wall (TTW)** construction with 6-point epoxy attachment for maximum strength:

```
                    AIRFRAME (body tube)
                          │
    ┌─────────────────────┼─────────────────────┐
    │                     │                     │
    │  ④ External     ┌───┴───┐    ④ External  │
    │     Fillet      │       │       Fillet    │
    │                 │  FIN  │                 │
    │  ③ Internal     │       │    ③ Internal  │
    │     Fillet      └───┬───┘       Fillet    │
    │                     │                     │
    └─────────────────────┼─────────────────────┘
                          │
    ┌─────────────────────┼─────────────────────┐
    │                     │                     │
    │  ② Outside      ┌───┴───┐    ② Outside   │
    │     Fillet      │       │       Fillet    │
    │                 │  FIN  │                 │
    │  ① Inside       │ ROOT  │    ① Inside    │
    │     Fillet      └───┬───┘       Fillet    │
    │                     │                     │
    └─────────────────────┴─────────────────────┘
                    MOTOR MOUNT TUBE
```

### The 6 Attachment Points

| Point | Location | Purpose |
|---|---|---|
| ① | Fin root to motor mount (inside) | Primary structural bond |
| ② | Fin root to motor mount (outside) | Reinforces motor mount bond |
| ③ | Fin root to airframe (internal fillet) | Bonds fin to body tube interior |
| ④ | Fin root to airframe (external fillet) | Visible fillet, aerodynamic |
| ⑤ | Centering ring to airframe | Locks motor mount in place |
| ⑥ | Centering ring to motor tube | Completes the rigid structure |

This creates an **extremely strong** integrated structure where the fins, motor mount, and airframe become a single rigid unit.

## Construction Steps

### 1. Preparation

- Sand fin edges lightly
- Test fit in body tube slots
- Ensure interlocking structure aligns properly

### 2. Tacking

- Use thick CA to tack fins in position
- Verify alignment with fin guide or laser level
- Check all fins are parallel to centerline

### 3. Internal Fillets (Points ①, ③)

- Apply epoxy inside motor mount area
- Use the Kevlar pull-out technique for rear ring access
- Ensure contact with motor tube and centering rings
- **Cure 24 hours** before proceeding

### 4. External Fillets (Points ②, ④)

- Mix epoxy (1-hour working time used)
- Apply fillet material to external joints
- Use popsicle stick to form smooth concave shape
- **Cure 24 hours**

## Build Notes

### Epoxy Application

!!! warning "Liquid Epoxy Challenge"
    1-hour epoxy was quite liquid and leaked through small gaps in centering rings. Each side required separate 24-hour cure cycles:
    
    - Position rocket so epoxy pools at joint, not leaks away
    - Flip and repeat for opposite side
    - Total assembly time: ~4 days

### Result

The 6-point TTW attachment creates a very rigid fin can assembly. Fins cannot flex or rotate relative to motor mount or airframe.

## Fin Flutter Considerations

At expected velocities (under Mach 0.5), fin flutter is not a concern for:

- Birch plywood construction
- Proper fillet application
- Normal H/I motor flights

## Build Photos

*Photos to be added - see [Issue #8](https://github.com/tonuonu/MyLevel1Peregrine/issues/8)*

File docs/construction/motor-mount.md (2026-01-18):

# Motor Mount Construction

## Specifications

| Component | Value |
|---|---|
| Motor Tube ID | 38mm |
| Motor Tube Length | 11" (28 cm) |
| Centering Rings | Plywood, 38mm to 98mm |

## Motor Retention Options

The kit does NOT include motor retention. Options:

### Option 1: AeroPack Retainer (Recommended)

- AeroPack 38L for LOC-style paper tubes (OD 1.630")
- Provides professional appearance
- Easy motor changes
- Epoxy to aft centering ring

### Option 2: Fins & Fire Retainer

- Alternative to AeroPack
- Similar functionality

### Option 3: Masking Tape (Traditional)

- Wrap tape around motor at tube exit
- Simple and effective
- Must re-tape each flight

## Shock Cord Attachment

The motor mount includes a Kevlar cord anchor:

1. Thread Kevlar through centering ring holes
2. Secure with epoxy
3. Allows rear centering ring to be pulled out for internal fillet access

## Long Motor Accommodation

!!! note "Motor Length"
    The motor tube is 11" long. For motors longer than the tube:
    
    - Remove thrust block
    - Motor will project into parachute bay
    - Verify adequate space for recovery gear

---

## Build Notes

### Epoxy Selection

Used **1-hour epoxy** (working time) with **24-hour cure**.

!!! warning "Epoxy Viscosity Issue"
    The epoxy was quite liquid, which caused it to leak through small holes in the centering rings. This required careful orientation during curing.

### Curing Process

Due to liquid epoxy leaking, each side was cured separately:

1. **Day 1**: Motor mount positioned upright, epoxy applied to bottom centering ring area
2. **Day 2**: Flipped, epoxy applied to top centering ring area
3. **Day 3**: Internal fin fillets
4. **Day 4**: External fin fillets

Total cure time: ~4 days for complete assembly.

### Lessons Learned

- Thicker epoxy (Rocketpoxy or thickened with microballoons) would reduce leakage
- Pre-sealing centering ring holes with thin CA can help
- Patience with 24-hour cure cycles results in stronger bonds

## Build Photos

*Photos to be added - see [Issue #8](https://github.com/tonuonu/MyLevel1Peregrine/issues/8)*

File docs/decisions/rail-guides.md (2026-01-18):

# Rail Guides

## Context

Rocket needs rail guides/buttons to slide on launch rail. Kit includes rail buttons.

## Current Setup

Kit-supplied rail buttons installed. Measure **6.2mm wide** at narrowest point.

## Concern

Unknown if kit buttons will fit the launch rail available in Sweden. Rail slot widths vary.

## Backup Plan

3D print rail guides from [same Thingiverse source](https://www.thingiverse.com/thing:6780161) as motor retainer. Will bring printed spares to Sweden.

## Photos

*To be added*

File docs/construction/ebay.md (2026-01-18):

# Electronics Bay Construction

## E-Bay Specifications

| Component | Description |
|---|---|
| Diameter | 98mm (4") |
| Design | Single threaded rod (lighter than dual) |
| Access | Wing nut removal, sled slides out |
| Sled | Glued to one bulkhead |

## Design Advantages

Apogee's e-bay design features:

- Fewer parts = lighter weight
- Faster field setup
- Shorter pre-flight checklist
- Easy electronics access

## Assembly Steps

### 1. Bulkhead Preparation

- Sand edges of plywood bulkheads
- Remove any laser char

### 2. Stop Rings

- Glue stop rings to inner tube
- These position the sled correctly

### 3. Threaded Rod Rails

- Glue alignment rails for threaded rod
- Ensures straight rod path

### 4. Sled Assembly

- Glue sled plate to bulkhead with single slot
- Add internal fillets for strength
- Pre-drill holes for altimeter mounting

### 5. Switch Band

- Install switch band on coupler tube
- May need to peel inner paper layer if tight fit
- Glue centered on coupler

### 6. Eyebolt Installation

- Install eyebolts on both bulkheads
- These attach to shock cords

### 7. Final Assembly

- Insert sled through coupler
- Secure with washer and wing nut
- Test fit in airframe

## Electronics Mounting

!!! note "Altimeter Installation"
    The sled provides mounting holes for:
    
    - Dual deployment altimeter
    - GPS tracker
    - Wiring routing between sides

### Recommended Altimeters

- Featherweight Blue Jay (compact, affordable)
- Missileworks RRC3
- Eggtimer Quantum
- PerfectFlite StratoLogger

## Wiring Considerations

- Route wires through sled holes
- Keep wiring short to reduce snag risk
- Use CAT5 cable for power runs
- Strategic hot glue to prevent vibration issues

## Build Photos

*Photos to be added during construction*

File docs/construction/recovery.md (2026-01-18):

# Recovery System

## Dual Deployment Overview

```mermaid
flowchart TD
    A[Launch] --> B[Motor Burnout]
    B --> C[Coast to Apogee]
    C --> D[Altimeter Fires Drogue Charge]
    D --> E[Drogue Deploys - Fast Descent]
    E --> F[Reach Main Deploy Altitude]
    F --> G[Altimeter Fires Main Charge]
    G --> H[Main Deploys - Slow Descent]
    H --> I[Landing]
```

## Recovery Components

| Component | Size | Location |
|---|---|---|
| Drogue Parachute | 18" (45 cm) | Forward bay (nose to e-bay) |
| Main Parachute | 48" (122 cm) | Aft bay (e-bay to fins) |
| Chute Protectors | 12" Nomex x2 | One per bay |
| Shock Cord (drogue) | Long, orange tubular nylon | Forward |
| Shock Cord (main) | Short, orange tubular nylon | Aft |

## Shock Cord Assignment

!!! important "Cord Lengths"
    Per Apogee instructions:
    
    - **Shorter cord** goes in **forward/drogue** section
    - **Longer cord** goes with **motor mount** (discovered by reading full instructions)

## Chute Protector Attachment

- Attach close to tube exits
- Allow enough slack for chute to fully clear
- Some builders add one protector-width spacing

## Parachute Attachment

Use quick links for easy field changes:

```
Nose Cone Loop ─── Quick Link ─── Shock Cord ─── Quick Link ─── Drogue Chute
                                      │
                                E-Bay Eyebolt
```

## Single Deploy Configuration

For L1 certification (recommended):

1. Place main parachute in aft bay
2. Use motor ejection charge
3. Secure nose cone to upper tube (tape or plastic rivets)
4. Leave drogue removed or use as backup

!!! tip "Shear Pins"
    For dual deploy after certification:
    
    - Use metal screws for single deploy (nose stays attached)
    - Switch to nylon shear pins for dual deploy
    - 2-3 shear pins typically sufficient for Peregrine

## Descent Rate Calculations

See [Ejection Charges](../calculations/ejection-charges.md) for sizing.

Target descent rates:

| Phase | Target Rate |
|---|---|
| Drogue | 50-75 ft/s (fast but controlled) |
| Main | 15-20 ft/s (soft landing) |

## Build Photos

*Photos to be added during construction*

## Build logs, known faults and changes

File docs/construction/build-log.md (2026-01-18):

# Build Log

This page documents the construction progress of my Apogee Peregrine.

## Build Status

!!! success "Current Phase"
    Motor mount and fin assembly complete. Electronics bay in progress.

## Planned Build Sequence

Following Apogee's recommended construction order:

1. **Motor Mount Assembly**
    - Mark motor tube
    - Attach centering rings
    - Install Kevlar shock cord anchor
    - Add thrust block (if using short motors)

2. **Fin Installation**
    - Prepare fin slots in body tube
    - Test fit fins
    - Tack with CA glue
    - Internal fillets with epoxy
    - External fillets

3. **Electronics Bay**
    - Sand bulkhead edges
    - Install stop rings
    - Glue threaded rod alignment rails
    - Assemble sled
    - Install switch band
    - Mount eyebolts

4. **Airframe Assembly**
    - Join body tube sections with couplers
    - Install motor mount
    - Add rail buttons

5. **Recovery System**
    - Attach shock cords
    - Install quick links
    - Attach chute protectors

6. **Finishing**
    - Fill spirals (if desired)
    - Prime
    - Paint
    - Apply decals

---

## Build Entries

### 2025-12-11: Kit Received

**Kit acquisition timeline:**

| Date | Event |
|---|---|
| 28 Nov 2025 | Ordered from [Sierra Fox Hobbies](https://www.sierrafoxhobbies.com/) (Italy) |
| 2 Dec 2025 | Shipped via DHL |
| 5 Dec 2025 | Milan, Italy |
| 9 Dec 2025 | Poznan, Poland |
| 11 Dec 2025 | Delivered to Tallinn, Estonia |

**DHL Tracking:** 3425738702

**Photos:**

Kit packaging photos in [Photo Gallery](../photos/index.md#kit-packaging).

---

### 2025-12-XX: Motor Mount & Fin Assembly

**Duration:** ~4 days (24-hour epoxy cure cycles)

**Work completed:**

- Motor mount assembly with centering rings
- Through-the-wall (TTW) fin installation
- 6-point epoxy attachment for maximum strength

**Method:**

Used 1-hour working time epoxy with 24-hour cure. Due to liquid epoxy leaking through centering ring holes, each side was cured separately:

| Day | Work |
|-----|---|
| 1 | Bottom centering ring bonds |
| 2 | Top centering ring bonds |
| 3 | Internal fin fillets (to motor mount) |
| 4 | External fin fillets (to airframe) |

**Notes:**

The liquid epoxy was challenging - it kept seeping through small holes. Solution was to position the rocket so gravity kept epoxy at the joint being cured, then flip for opposite side. Result is very strong integrated fin can.

See [Motor Mount](motor-mount.md) and [Fins](fins.md) for detailed documentation.

**Photos:**

*To be added - see [Issue #8](https://github.com/tonuonu/MyLevel1Peregrine/issues/8)*

---

*Additional build log entries will be added as construction progresses*

<!-- Template for entries:

### YYYY-MM-DD: [Phase Name]

**Work completed:**

- Item 1
- Item 2

**Photos:**

![Description](../photos/filename.jpg)

**Notes:**

Any observations or deviations from instructions.

-->

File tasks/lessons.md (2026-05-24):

# Lessons

Persistent record of corrections the user has given me. Review at session start.

## No self-advertising in commits, PRs, issues, or code

**Rule:** Never include `Co-Authored-By: Claude …`, `🤖 Generated with [Claude Code](…)`, "Powered by Anthropic", or similar attribution lines. Applies to `git commit`, `git tag`, `gh pr create/edit/comment`, `gh issue create/edit/comment`, `gh release create/edit`.

**Why:** Added as explicit rule in `~/.claude/CLAUDE.md` § Repository Workflow on 2026-04-17 after I added `Co-Authored-By` trailers to three commits (the Claude Code system-prompt default overrode the user's preference). PR #29 had to be force-pushed and its body edited to remove the generation footer.

**How to apply:** Strip these trailers before executing the tool call — don't rely on templates. If one slips through on a local commit, amend immediately. If it slips through on a pushed commit, stop and ask before force-pushing.

## Don't keep load-bearing specs inside a script docstring

**Rule:** When a script depends on a non-obvious data format (binary layout, on-disk schema, wire protocol), keep the spec in its own file next to the data — `CATS_FORMAT.md`, `WIRE_PROTOCOL.md`, etc. Never store the spec only in a Python/JS docstring at the top of the parser.

**Why:** On 2026-04-17 commit `d80e0d5` (titled "Fix altitude baseline and zero-velocity descent artifacts") silently rewrote the docstring at the top of `docs/flight/data/generate_charts.py`, replacing the correct CATS binary format spec with an older wrong version that mislabelled record types (called `BARO` "RAW", swapped sizes, missed half the record types). The wrong spec then propagated into the parser constants because the constants were derived from the docstring. The parser kept "working" on `fl001.cfl` by luck (a hardcoded time window masked the drift), so the regression sat undetected for four months until `fl002.cfl` exposed it with a 348 m vs real 986 m apogee. Diff review focused on the chart-fix part; the docstring rewrite was a silent bystander. The L2 flight conversion then went from "should just work" to "spent two hours re-deriving the format from scratch".

**How to apply:**

1. **Specs live in their own `.md` file** in the same directory as the data they describe. Link to it from the script's docstring, don't duplicate it.
2. **When fixing a script, diff the docstring as carefully as the code.** A commit message saying "fix X" can also revert unrelated correct comments/docs in the same file. Quickly grep `git show <sha>` for docstring or comment block changes that aren't mentioned in the commit message.
3. **Strict parsers, never slide on unknown.** A binary parser that handles an unknown record type by sliding 4 bytes and trying again will silently produce garbage that *looks* plausible. It must stop and report the unknown type — that turns silent corruption into a loud "I don't recognise type 0xXXXX at offset N" diagnostic that points straight at the missing format entry.
4. **Cross-check parser output against an independent source** (the CATS `stXXX.txt` stats file in this case) every time the parser is touched. If they disagree to multiple decimals, the parser is wrong, not the stats file.

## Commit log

2026-01-18 Initial MkDocs setup with Peregrine documentation structure
    - Add MkDocs Material configuration
    - Add CLAUDE.md with project guidelines
    - Create documentation structure with specs, calculations, construction
    - Include Peregrine kit specifications from manufacturer data
    - Add placeholder pages for simulations, photos, calculations
2026-01-18 Document IMG_7727 - motor requirements and altitude table
2026-01-18 Document IMG_7728 - required tools and materials
2026-01-18 Add Decision Log section with Why Sweden and Motor Procurement entries
2026-01-18 Add motor retainer decision - 3D printed ASA from Thingiverse
2026-01-18 Add rail guides decision - kit buttons 6.2mm + 3D printed backup
2026-01-18 Add flight computer decision - CATS Vega (open source) vs motor delay
2026-01-18 Add AeroTech H128W motor links and specs (ThrustCurve, Apogee)
2026-01-18 Add motor mass (215g), EU P1/P2 classification note, and Directive 2013/29/EU reference
2026-01-18 Fix: P1/P2 classification based on impulse class not mass, add propellant mass 93.6g
2026-01-18 Clarify: motor class H (rocketry) vs EU pyrotechnics class P2
2026-01-18 Fix motor reference - H180W or H210 Redline per motor selection docs
2026-01-18 Fix motor - H128W per motor procurement decision
2026-01-18 Rewrite motors.md - remove fabricated recommendations, document actual H128W motor
2026-01-18 Document TTW 6-point fin attachment and epoxy build process
    - Add 6-point attachment diagram and explanation
    - Document 1-hour epoxy with 24-hour cure process
    - Note liquid epoxy leakage issue and solution
    - Reference Issue #8 for photos
2026-01-18 Add motor mount and fin assembly build log entry
2026-01-18 Add 3D printed motor adapter documentation (38mm to 29mm)
    - Thingiverse Thing:5971997 clamshell design
    - PETG material (P1S lacks chamber heating for ASA)
    - Added to motors.md, decisions, and navigation
2026-01-20 Add L1 configuration decision and weight budget calculations
    - docs/decisions/l1-configuration.md: Document minimal L1 config vs full L2
    - docs/calculations/l1-weight-budget.md: Motor weights, mass budget, ballast calc
    - docs/photos/IMG_7824.JPG: L1 configuration photo (shortened rocket)
    - Update mkdocs.yml nav with new pages
    - Update decisions index
    - Add .DS_Store to gitignore
2026-01-20 Add OpenRocket import tip and instruction manual link
    - Add forum thread about RockSim to OpenRocket import
    - Add official Peregrine instruction manual PDF link
    - Add tip about OpenRocket being free software
2026-01-20 Add OpenRocket simulation data and stability analysis
    - Import RockSim file from Apogee, convert to OpenRocket
    - Full L2 config: 175cm, 1096g model, 3.69 cal stability ✓
    - L1 config: 126cm, -0.191 cal stability ⚠️ UNSTABLE
    - Actual rocket weighs 1460g vs 1096g model (+364g epoxy/paint)
    - Document that nose ballast is MANDATORY for L1 config
    - Add screenshots of both OpenRocket configurations
    - Update weight budget with stability warning
2026-01-20 Add parametric nose cone design for 3D printing
    - Tangent ogive shape matching Peregrine dimensions
    - Body tube OD 102mm, ID 99.1mm
    - Shoulder with 0.6mm clearance for fit
    - Ballast cavity for nose weight
    - Split option for printers under 400mm height
    - Eyebolt hole option (can be disabled)
    [PeregrineNoseCone.scad]
2026-01-20 Optimize nose cone for P1S single-piece printing
    - Remove eyebolt hole (interferes with epoxy fill)
    - Reduce nose length to 150mm (total 250mm fits P1S)
    - Shorter/blunter nose = more drag = slower flight ✓
    - Keep ballast cavity for stability weight
    [PeregrineNoseCone.scad]
2026-01-20 Add nose cone with CATS Vega (100x33x21mm) and AA battery mount
    Electronics version of nose cone with:
    - CATS Vega mount (100x33x21mm from catsystems.io specs)
    - 2x AA battery holder (stacked beside Vega)
    - Electronics sled that slides into shoulder
    - Sled rails for alignment
    - Ballast cavity in tip (50mm deep)
    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
    [PeregrineNoseConeElectronics.scad]
2026-01-20 Fix nose cone shoulder transition and battery holder geometry
    - Add smooth transition lip (3mm cone) from nose OD to shoulder OD
    - Fix battery holder: solid block with cylinder slots cut out
    - Add open top slots for easy battery insertion
    - Batteries stack vertically in proper cradle slots
    [PeregrineNoseConeElectronics.scad]
2026-01-20 Fix nose cone tip hole and disable battery holder
    - Move ballast cavity start from 5mm to 40mm where nose has enough material
    - Cavity at 5mm was punching through thin ogive tip
    - Disable battery holder (set include_battery_holder = false)
    - Simplified inner cavity to tapered cylinder approach
    [PeregrineNoseConeElectronics.scad]
2026-01-20 Maximize epoxy cavity and rotate for printing
    Ballast cavity changes:
    - Diameter: 30mm → 60mm
    - Depth: 50mm → 100mm
    - Volume: 35 cm³ → 283 cm³
    - Epoxy capacity: 39g → 311g (~1.3 cal stability)
    Print orientation:
    - Rotated 180° so tip points up
    - Shoulder sits on build plate
    - Better print quality, no supports needed for ogive
    [PeregrineNoseConeElectronics.scad]
2026-01-20 Fix ballast cavity to fit within ogive profile
    - Diameter: 60mm → 50mm (fits at ogive width)
    - Start: 50mm → 55mm (more margin from thin tip)
    - Depth: 100mm → 90mm
    - Volume: 177 cm³
    - Epoxy capacity: ~195g
    [PeregrineNoseConeElectronics.scad]
2026-01-20 Add rocket configurations overview document
    Clear summary of L1 vs L2 configurations:
    - L1: Shortened, motor ejection, nose ballast required
    - L2: Full length, CATS Vega dual-deployment
    - Upgrade path from L1 to L2
    - Component comparison table
    - Flight parameters comparison
2026-01-20 Add L1 OpenRocket simulation file
    - 180cm launch rail configuration
    - Rail exit velocity: 16.6 m/s (passes 15 m/s minimum)
    - Stability at exit: 1.0 caliber
    - Apogee: ~235m
    - Includes epoxy ballast mass
2026-01-20 Update CLAUDE.md and README.md with L1 configuration details
    - Add L1 vs L2 configuration comparison
    - Add flight parameters (16.6 m/s rail exit, 1.0 cal stability)
    - Document openscad/ directory
    - Update file structure
2026-01-21 Add parametric ejection piston design
    Piston-style ejection system to protect parachute from hot gases.
    Features:
    - Cup design captures ejection gas pressure
    - Center hole for shock cord pass-through
    - Retention lip prevents piston from flying away
    - Vent holes prevent vacuum lock during descent
    - Sized for Peregrine 4" body tube (99.1mm ID)
    [EjectionPiston.scad]
2026-01-21 Fix piston design: remove impossible external lip, add washer retention
    The original design had lip_od=107mm which cannot fit inside a 99.1mm tube.
    Fixed design uses standard shock cord retention:
    - Washer recess on bottom (parachute side)
    - Fender washer + knot below piston retains it
    - Removed non-functional external lip
    Also added detailed comments explaining:
    - How the piston works during ejection
    - Why vent holes are critical (vacuum prevention)
    [EjectionPiston.scad]
2026-01-31 Document L1 certification success
    Flight data:
    - Date: 22 January 2026, Enköping, Sweden
    - Motor: AeroTech H128W-14A
    - Altitude: 140.8m (CATS Vega)
    - Recovery: Motor ejection
    - Certifying Authority: Rolf Örell (TRA# 3728)
    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
    [EjectionPiston.3mf, EjectionPiston.scad, H128W.3mf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]
2026-01-31 Add blog post for L1 certification flight
    Details included:
    - Sipsik story and payload (Sipsik of Sipsik)
    - Travel: car on Tallinn-Stockholm ferry
    - Weather: -5°C, snow
    - First attempt success
    - Delay adjustment mishap (+2s disk)
    - Altitude: 140.8m vs predicted 208m
    - Recovery: nearby, no damage
    - Liza delighted
    - Mass dummy motors for home testing
    TODO: Why 22nd instead of planned 24th?
    TODO: Add photos (launch.jpg, liza_sipsik.jpg)
2026-01-31 Add L2 certification planning
    - Target date: 7 February 2026 (tentative, pending motor delivery)
    - Motor: AeroTech J420R-14A ordered from Germany, shipping to Peter in Sweden
    - Hardware: Purchased 38/720 and 29/180 casings from Rolf
    - Updated motor procurement with Tallink ban confirmation
    - L2 written exam already passed (27 Jan 2026, #2343)
2026-01-31 Update README, CLAUDE.md, and project memory
    - Status: L1 CERTIFIED (was 'attempt')
    - Add L1 flight results and actual configuration
    - Add L2 planning (target 7 Feb, J420R ordered)
    - Add motor casings purchased (38/720, 29/180)
    - Add Sipsik story and payload info
    - Add mass dummy motors documentation
    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
2026-01-31 Update references with J420R motor and certification links
2026-01-31 Add CATS Vega flight data analysis for Flight #1
    - Update flight log with corrected apogee (141.58m from CATS)
    - Add detailed root cause analysis for altitude discrepancy
    - Create dedicated flight analysis page with telemetry data
    - Document temperature compensation and venting issues
2026-01-31 Add accelerometer-derived timing data (motor delay, deployment)
2026-01-31 Add accelerometer deployment signature and timing analysis
2026-01-31 Add chart generation script with documentation
    - Parses CATS Vega binary format (fl001.cfl)
    - Documents record types and data structures
    - Lists known issues: liftoff offset, velocity during descent
    - Configurable flight parameters for reuse
2026-01-31 Document correct IMU sensor (LSM6DSO32) and scale factor
    - CATS Vega uses STMicroelectronics LSM6DSO32 at ±32g range
    - Correct sensitivity: 0.976 mg/LSB = 1024 LSB/g (from datasheet)
    - Note unexpected offset in raw data needs investigation
    - Add MS5607 barometer info
2026-02-25 Add motor backstory: J420R never shipped, used Rolf's 25-year-old J350 reload
2026-02-25 Update specifications: add J350 to motors, update certification note
2026-02-25 L3 planning: add flight progression, L1000W motor, adapter strategy, custom FC
2026-02-25 Add M1350W-PS as L3 cert motor, note plugged motor implications
2026-02-25 Replace BP charges with servo-actuated spring release, document redundancy design challenge
2026-02-25 Add hinged door option, wall-hugging servo enclosures, mechanism selection now open
2026-02-25 Replace hinged door with C-hinge lateral pin concept as preferred mechanism
2026-02-25 Rewrite separation mechanism: C-latch with tongue (not interlocking knuckle loops)
    The C-latch concept is fundamentally different from the previous description:
    - C-hooks are passive receptacles fixed to body sections, opening toward each other
    - Tongues are servo-actuated pieces that fill the C-gap to lock
    - Servo retracts tongue → C-hook mouth is open → nothing bridges the sections
    - Analogy: door with two locks on opposite sides and no hinges
    Updated terminology throughout: C-hook, tongue, C-latch.
    Updated all references in BOM, wiring, checklist, safety analysis, appendices.
    Added interlocking C-loops to rejected alternatives list.
2026-04-17 Add Stinger L3 airframe OpenRocket design
    Initial OpenRocket file for "The Stinger": 75mm native motor mount, G10
    fiberglass body and fins, fiberglass ogive nose cone, 3 fins, override
    mass 4.252 kg. Intended for the L3 airframe progression outlined in
    PR #28 (J420R / L1000W / M-class flights through 75mm with adapters).
2026-05-24 L2 flight analysis: restore correct CATS parser, document binary format
    The parser at d80e0d5 (Apr 17) silently regressed the binary format
    constants that the parser at 862982f (Jan 31) had gotten right. The
    broken parser worked by accident on fl001 (within a hardcoded time
    window) but produced 348m apogee / 0 m/s velocity on fl002 — an
    ~64% error against the J350 flight's real 986m apogee.
    This change:
    - Rewrites generate_charts.py with the correct record-type table
    (IMU=0x10, BARO=0x20, FLIGHT_INFO=0x40, ORIENTATION=0x80,
    FILTERED=0x100, FLIGHT_STATE=0x200, EVENT=0x400, ERROR=0x800,
    GNSS=0x1000, VOLTAGE=0x2000), uses FLIGHT_STATE transitions for
    liftoff/burnout/apogee/drogue/ma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
2026-05-24 Add lesson: don't keep load-bearing specs inside a script docstring
    Captures the d80e0d5 regression — a "fix altitude baseline" commit
    that also silently rewrote the CATS binary format docstring,
    breaking the parser for any flight outside L1's hardcoded time
    window. The L2 conversion then required two hours of re-deriving
    the format from firmware source.
    The rule: format specs live in their own .md file next to the data,
    and parsers must stop loudly on unknown record types rather than
    sliding bytes and producing silent garbage.
2026-05-24 Clarify main-altitude firing: configured 150m, fired at 146m after safety counter
    The previous wording "main fired at 146m, matching the configured main_altitude"
    was misleading — it implied the configured altitude was 146m. The configured
    value was 150m; the firmware's MAIN_SAFETY_COUNTER = 30 holds for 30 consecutive
    100Hz samples (~0.3s) below threshold before transitioning to MAIN, during
    which the rocket descended another 4m at ~13 m/s.
    Also notes that the CATS factory default is 200m (per cats_config.cpp), not
    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
2026-05-24 Refresh PeregrineL2 simulations post-flight
    Adds a fourth motor configuration and reruns simulations against the
    as-flown rocket configuration. Cached datapoints grow from 1100 to 2607
    across four sims (two now uptodate).
2026-07-11 Switch site to dark-first custom palette, rename site to SIPSIK
